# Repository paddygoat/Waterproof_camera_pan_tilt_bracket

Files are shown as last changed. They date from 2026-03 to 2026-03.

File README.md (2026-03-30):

Waterproof Raspberry Pi Camera Pan-Tilt Mechanism

This project features a fully weather-proof pan and tilt camera bracket controlled by Bowden cables, specifically designed for MIPI cameras like those used with the Raspberry Pi.
Overview

<p align="center">
  Pan Tilt Mechanism
</p>

Traditional pan-tilt systems often have motors attached directly to moving parts, making weather-proofing difficult and expensive. This design moves the electric actuators remotely under a weather-proof canopy or enclosure, reducing both complexity and cost.
Key Features

    Remote Control: Controlled by linear actuators hidden safely away.

    Torsion Springs: Used to act against the cables, as Bowden cables typically only operate in "pull" mode.

    Weather-proof Enclosure: Includes a square IP68 enclosure for the camera.

    Durability: The design is "beefy" enough to survive a knock from a stray 3" tree branch.

Supplies
Hardware

    Bolts: 2x M5 x 70mm, 4x M5 x 40mm CS, 1x M5 x 25mm CS.

    Nuts: 7x M5 nyloc nuts.

    Cables: Bowden cables (1.5mm+sheath×3m) and 4x cable end lugs (OD 5mm x 7mm).

    Springs:

        1x 2mm THK, 7 coils, 90 degrees.

        2x 1.5mm THK, 4 coils, 180 degrees.

    Electronics: 500mm camera ribbon cable and a 20mm cable gland.

    Enclosure: Hammond 1554B2GYCL Watertight PC Enclosure (65×65×40mm).

3D Printed Parts

Most components are 3D printed in SLA resin (standard PLA is also used) for under $60.

<p align="center">
  CAD Diagram
</p>

    CAD Files: Available on GitHub.

    Note: The swivel connector must be built from stainless steel as plastic versions tend to snap under pressure.

Testing the Mechanism

Initial testing was performed by bolting the assembly to a pallet and using mole grips to simulate linear actuator movement.
Critical Findings:

    Cable Length: 200mm cables were too short and caused internal tension that interfered with movement. At least one meter of cable is recommended for final installation.

    Spring Selection: Trial and error is required. Overpowered springs stress components, while light springs cannot overcome cable friction.

    Pin Reinforcement: The tilt pin is a common failure point. This design uses a 3D-printed pin with a center hole, reinforced by sliding a 2mm spring steel rod inside.

Assembly Instructions
1. Base and Pan Mechanism

    Begin with the base disc. Slide a matching spring steel pin into the center hole of the 3D-printed pin to reinforce the plastic.

    Insert a nyloc nut into the hexagonal captive slot.

    Attach the Bowden cables using the metal lugs (screwed and soldered for security).

    Slot the two main pieces together and secure with a 25mm M5 bolt. Keep it loose enough for the discs to spin without friction.

    Connect the cable to the pin using the stainless steel swivel connector. Attach the heavy-duty spring (2mm THK) so it acts against the pin.

2. Tilt Mechanism

    Use a 70mm bolt and the two 1.5mm springs.

    Place the springs at either end of the bolt and secure with a nyloc nut.

    Ensure the mechanism takes a bit of force to push back; this ensures a steady camera.

3. Camera Enclosure and Weather-proofing

    Mount the Raspberry Pi AI camera inside the Hammond enclosure using a 3D-printed bracket.

    Pro Tip: Position the lens as close to the clear lid as possible to prevent glares and blurry spots.

    Pass the 16mm ribbon cable through the cable gland.

    To ensure a 100% waterproof seal, use a rubber O-ring and fill the inside of the gland with epoxy resin.

Project sponsored by PCBWay. https://www.pcbway.com/. Use these guys to get high quality parts for this project.

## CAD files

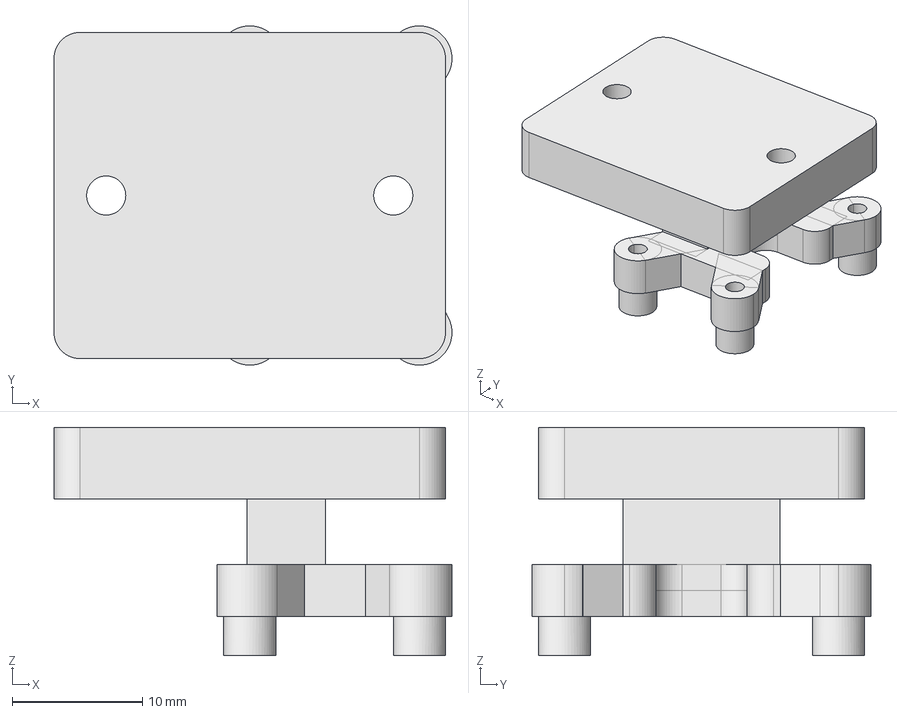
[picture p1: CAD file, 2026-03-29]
CAD_files/rpi_camera_mount_03.FCStd
30.5 x 26.0 x 17.5 mm

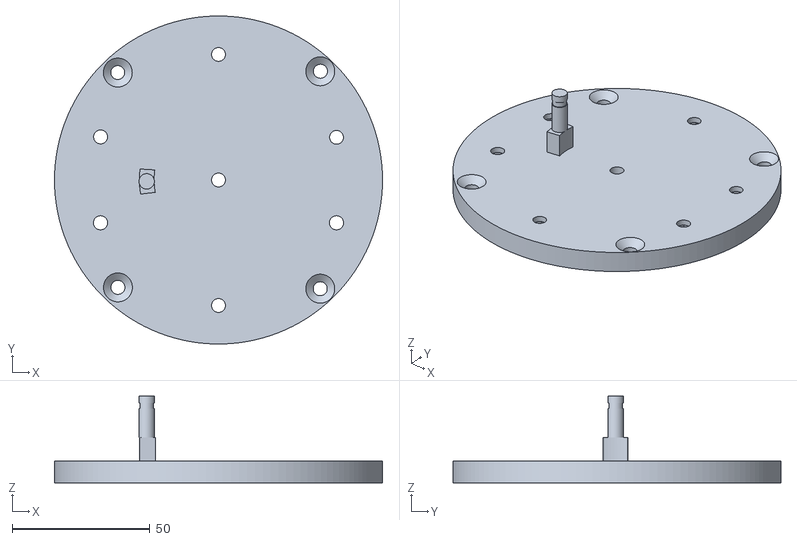
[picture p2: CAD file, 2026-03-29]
CAD_files/camera_tilt_bracket_60-LOWER_DISC.obj
119.3 x 119.2 x 31.5

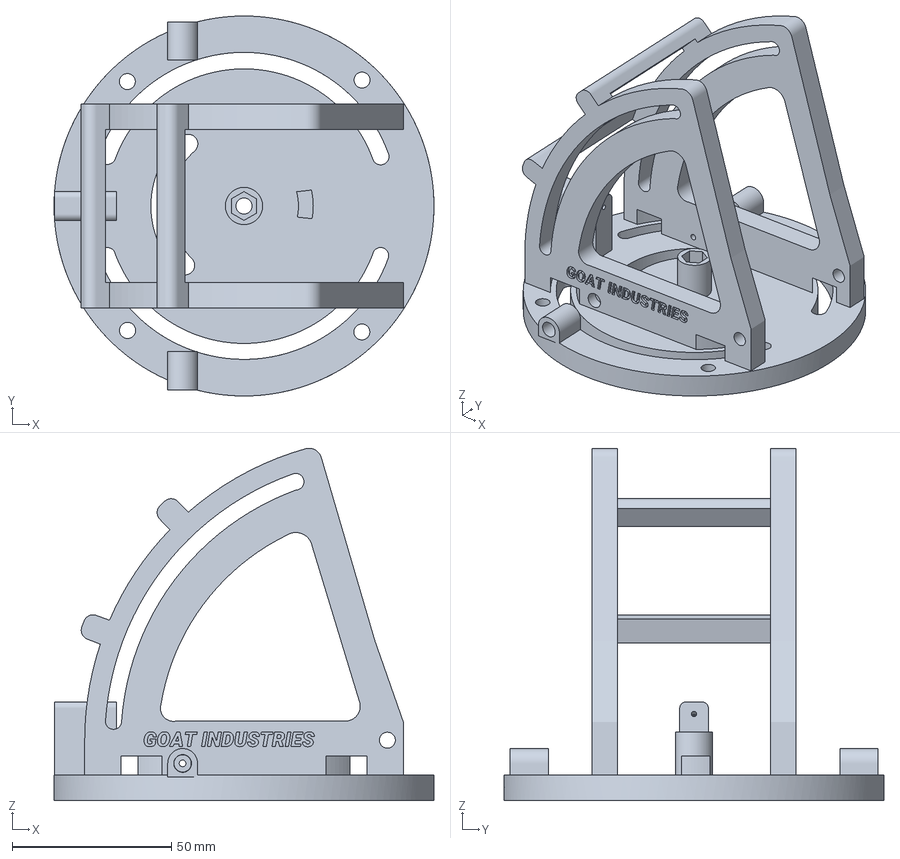
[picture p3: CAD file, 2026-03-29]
CAD_files/camera_tilt_bracket_66-OUTER006.3mf
119.3 x 119.3 x 110.6 mm

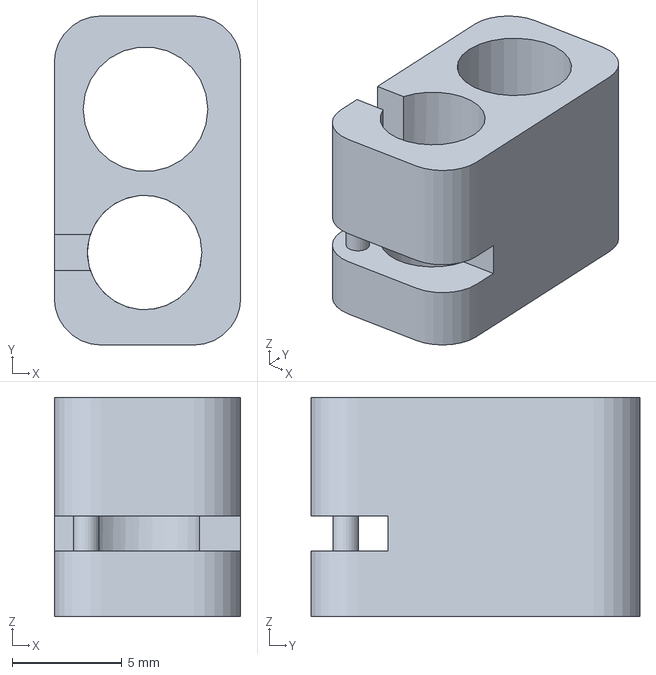
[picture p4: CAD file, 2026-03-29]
CAD_files/camera_tilt_bracket_66-Swivel_connector.3mf
8.50 x 15.0 x 10.0 mm

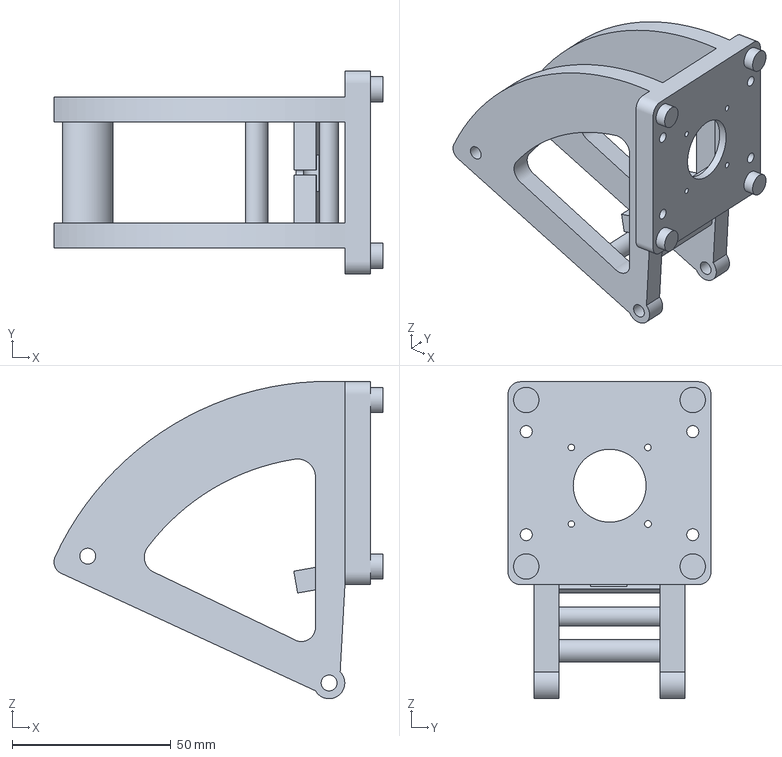
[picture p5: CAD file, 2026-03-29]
CAD_files/camera_tilt_bracket_66-INNER011.3mf
103.7 x 64.0 x 100.1 mm

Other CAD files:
CAD_files/rpi_camera_mount_03-Cut028.3mf
CAD_files/camera_tilt_bracket_67-LOWER_DISC_.3mf
CAD_files/camera_tilt_bracket_66-LOWER_DISC_.3mf
CAD_files/camera_tilt_bracket_60-LOWER_DISC_with_drill_guide_hole.3mf
CAD_files/camera_tilt_bracket_60-LOWER_DISC_with_drill_guide_hole.obj
CAD_files/camera_tilt_bracket_66-INNER011.obj
CAD_files/camera_tilt_bracket_66-LOWER_DISC_.obj
CAD_files/camera_tilt_bracket_66-OUTER006.obj
CAD_files/camera_tilt_bracket_66-Swivel_connector.obj
CAD_files/camera_tilt_bracket_67-LOWER_DISC_.obj
